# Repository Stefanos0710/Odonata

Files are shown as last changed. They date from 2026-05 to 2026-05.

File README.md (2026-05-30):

# Odonata

Odonata is an autonomous indoor drone controlled over a local network. I had the idea for the project, after I once bought a drone that broke after just two days because I struggled to control it manually. Sothat it doesn´t crash again, I decided to build a new,  autonomous drone and named it Odonata, after the Latin word for dragonfly.

The drone weighs about 300g and uses a 3S 11.1V 850mAh battery, giving it a flight time of roughly 5 minutes. With around 1100g of thrust, it achieves a 3:1 thrust-to-weight ratio, which allows precise flights. For navigation, it has 4 ToF (Time-of-Flight) sensors to track its position in the room, and it can perform controlled autonomous landings using a camera that detects AprilTags on the landing station. The landing station is designed with self-centering sticks, sothat even with a positioning error of about 1cm, the drone can still lands safely.

Odonata runs on a Raspberry Pi Zero 2W and a DarwinFPV flight controller, connected together via a custom PCB. With this setup the Pi can send and receive data using MAVLink commands (such as starting the motors, pitching, etc.). The project is split into two parts: the drone itself and a local server. The server hosts a web-based cockpit where you can monitor the drone, test the motors, and start-stop flights. Because it works locally, you can easily host the server on your laptop, PC, or a separate Raspberry Pi.

## Zine Poster

Here is the Zine poster of my project Odonata:

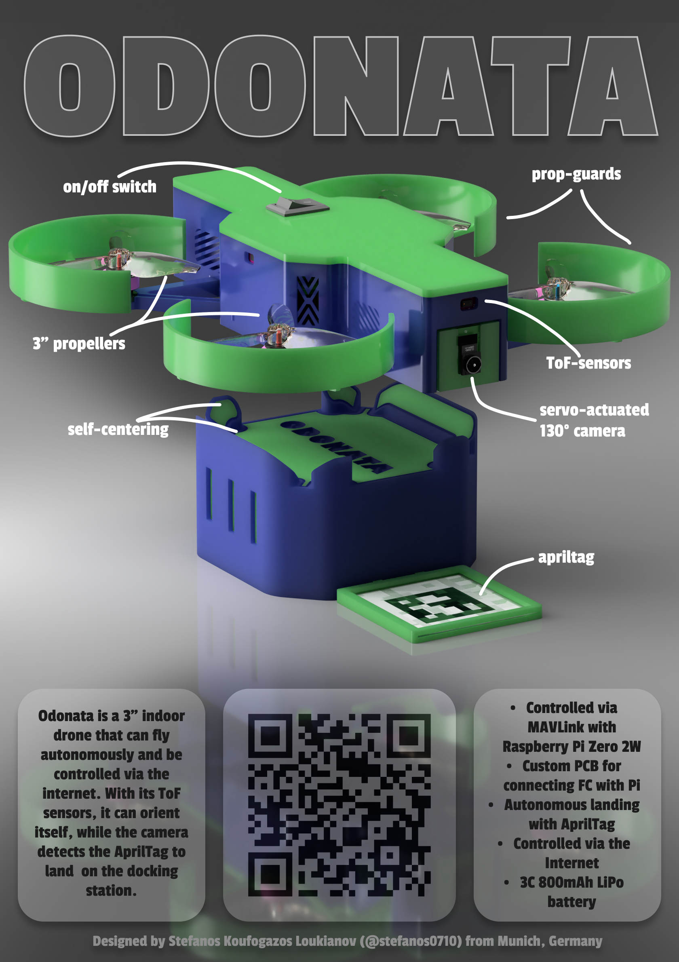
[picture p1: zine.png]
Odonata Zine


## Website/Cockpit

Here you can see the user interface of the cockpit where you can monitor the drone and send commands:
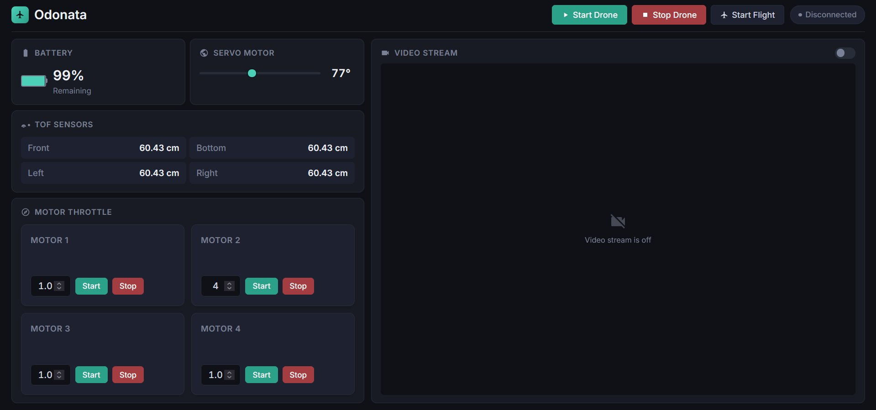
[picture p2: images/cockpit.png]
Cockpit


## CAD Model

The CAD design of Odonata is split into several parts, like the arms, the walls, the base, the cover, and the propguards. Everything is attached using M2 screws and heat inserts, or slide-ins and snap-fits. The .step, .stl and f3d/f3z files can be found at the /CAD directory. Here are some nice renders of the assembled drone:

(All parts were modeled and rendered in Autodesk Fusion 360)

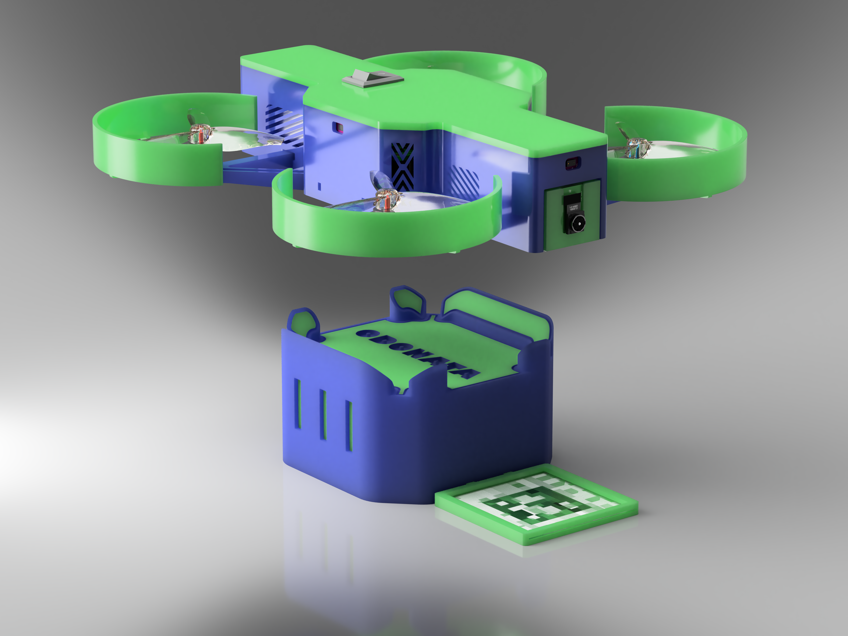
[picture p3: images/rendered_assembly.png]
Landing Station Assembly


<details>
<summary><b>Click here to view more renders</b></summary>

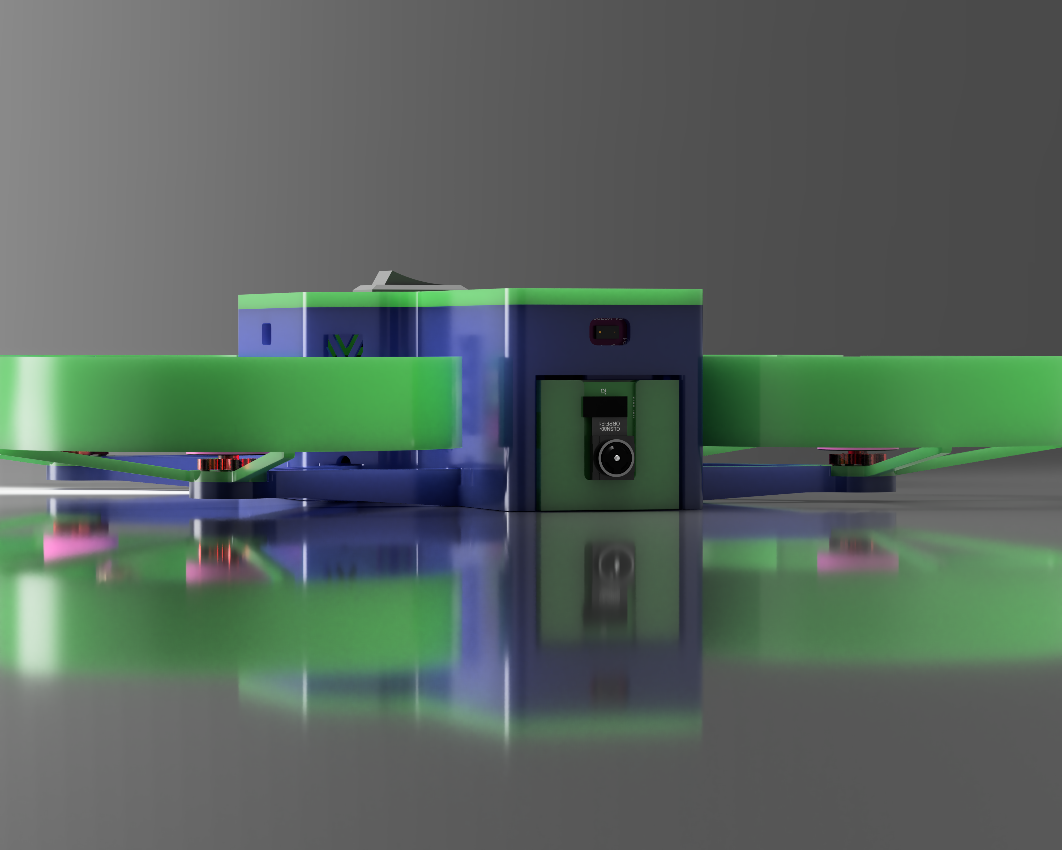
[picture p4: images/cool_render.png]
Cool Drone Render

Close Up Render
Drone on Floor

</details>

## PCB

This custom PCB is designed in KiCad and makes the flawless communication between the Flight Controller and the Raspberry Pi Zero 2W possible, and also connects the servo, the ToF sensors and camera to a working system. It uses a 4-layer design for the optimal routing and to ensure no noise on the power lines.

### Schematics

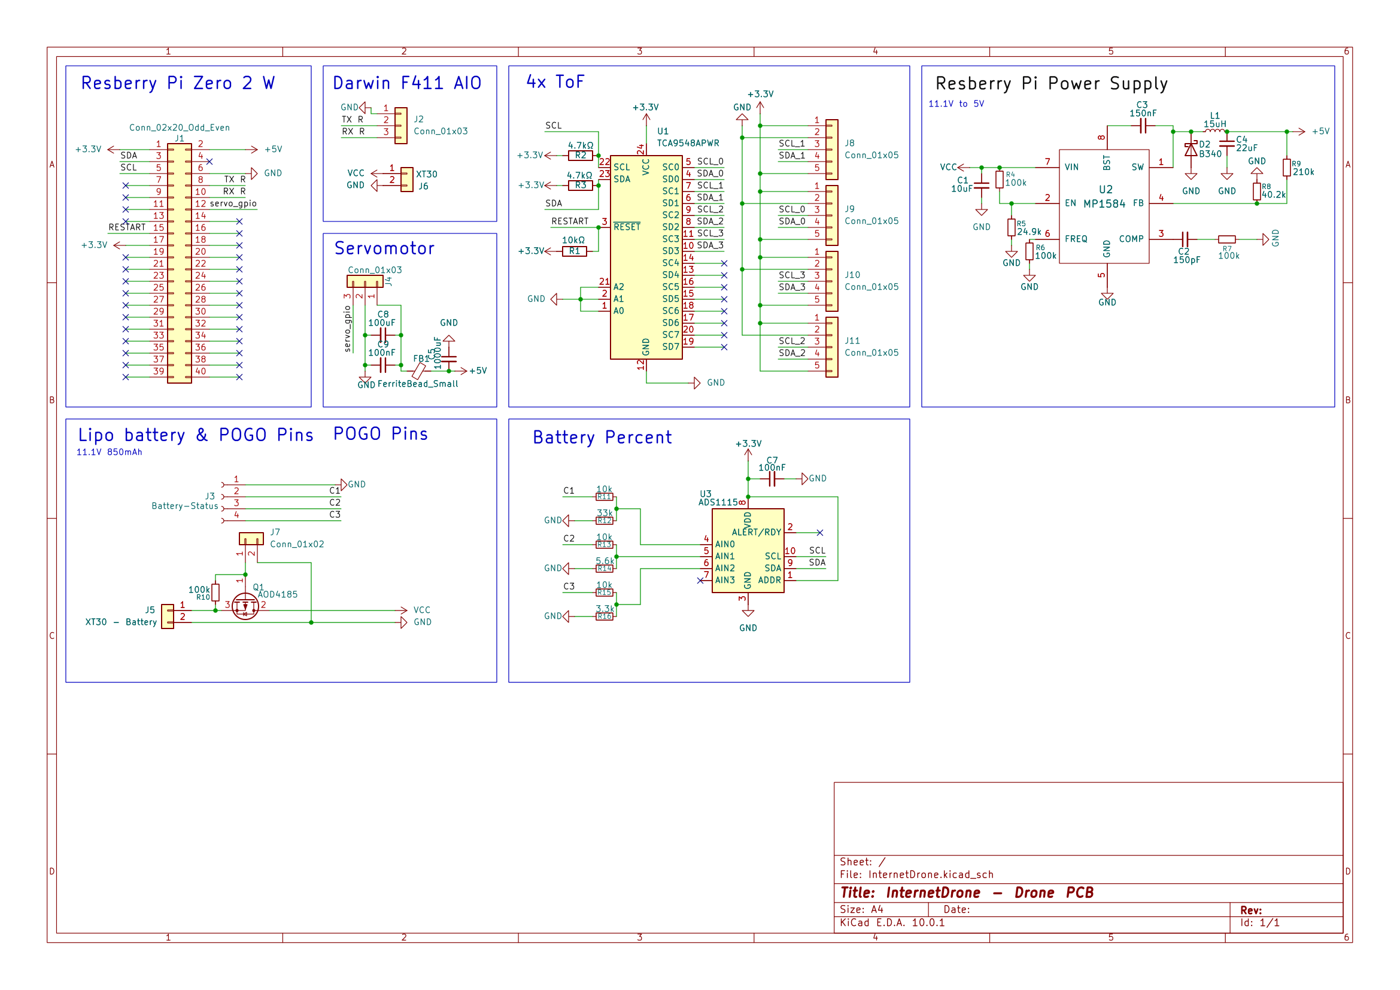
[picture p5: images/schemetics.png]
Schematics


### PCB-Layers

The PCB uses 4 layers: 1. TOP-Signal layer 2. GND layer 3. Power layer 4. Signal and GND layer

#### **1. Layer (Top-Signal)**

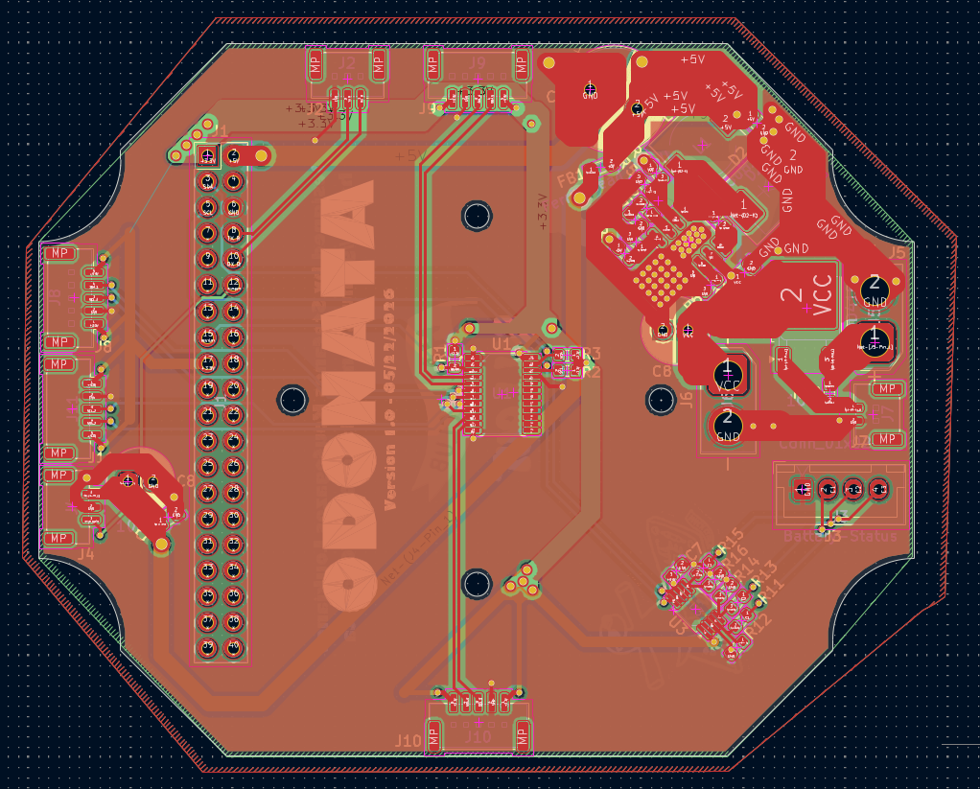
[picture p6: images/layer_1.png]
1. Layer


#### **2. Layer (GND)**

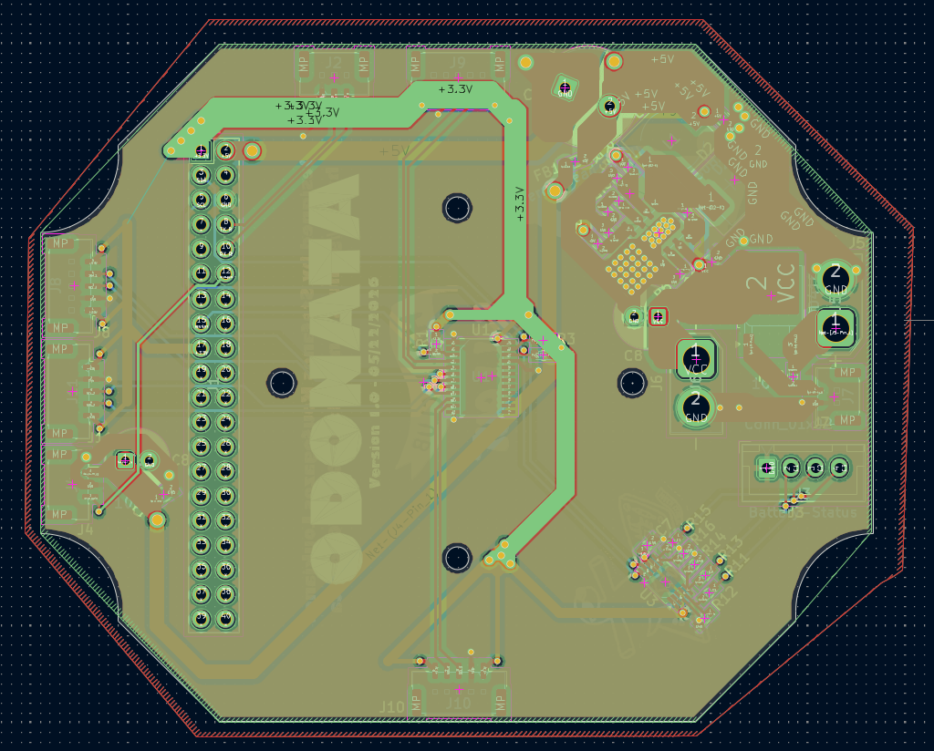
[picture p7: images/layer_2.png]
2. Layer


#### **3. Layer (Power)**

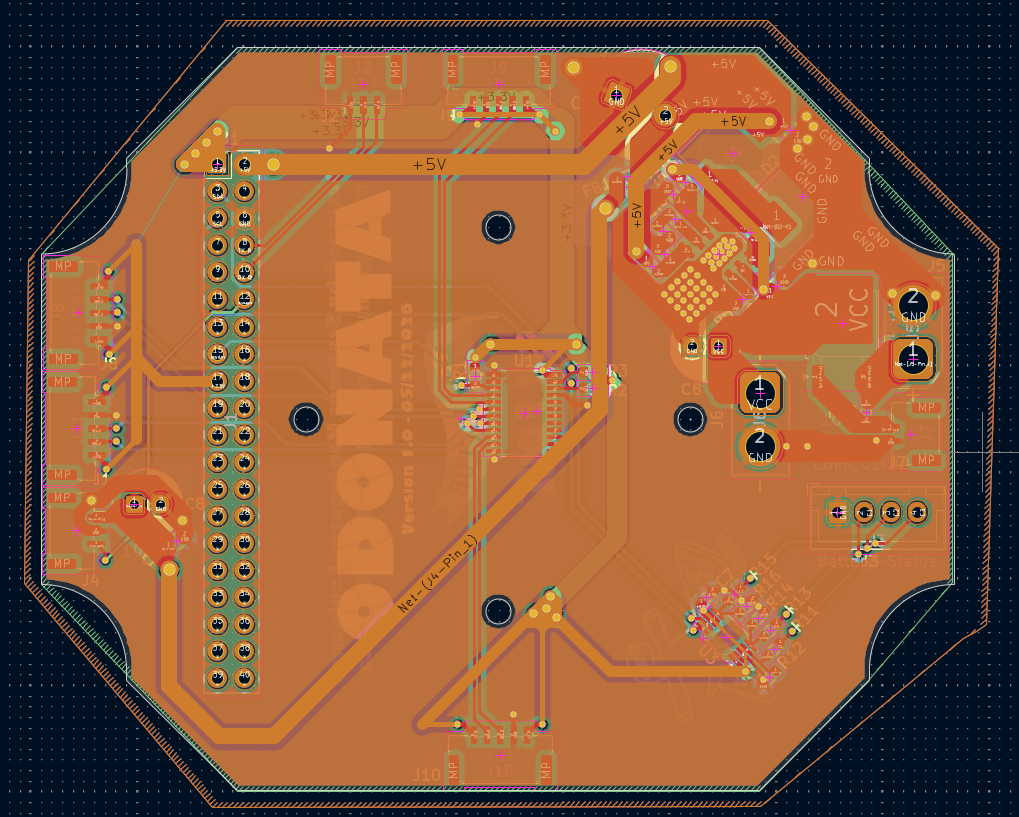
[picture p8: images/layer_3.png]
3. Layer


#### **4. Layer (Signal/GND)**

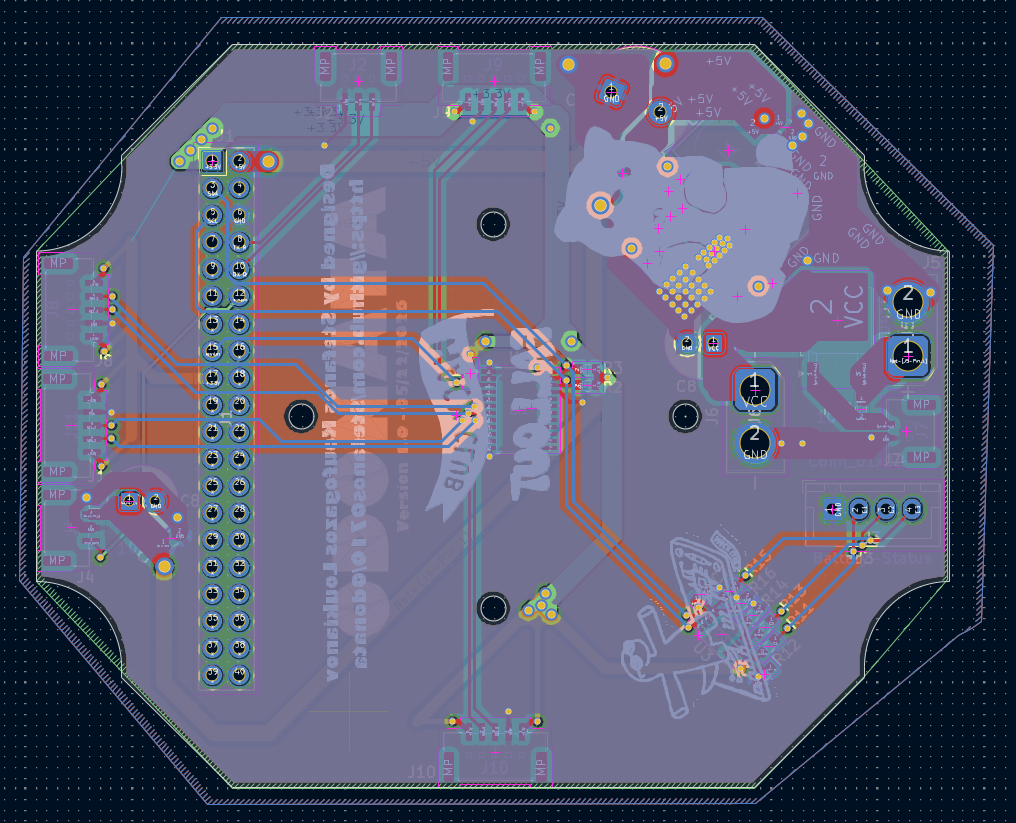
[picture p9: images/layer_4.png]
4. Layer


#### **PCB 3D-Rendering**

| Front | Back |
|---|---|
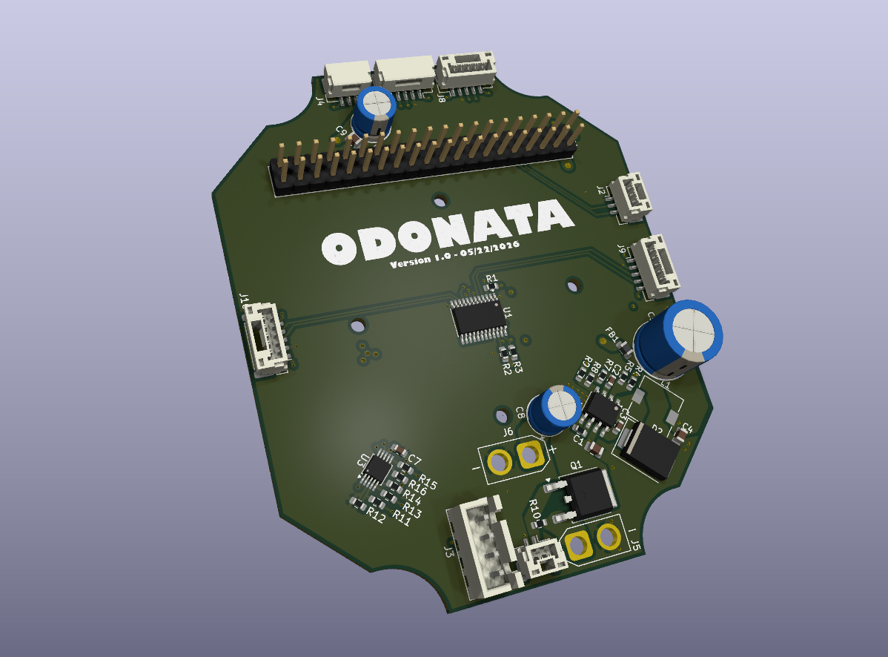
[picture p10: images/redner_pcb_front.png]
Front
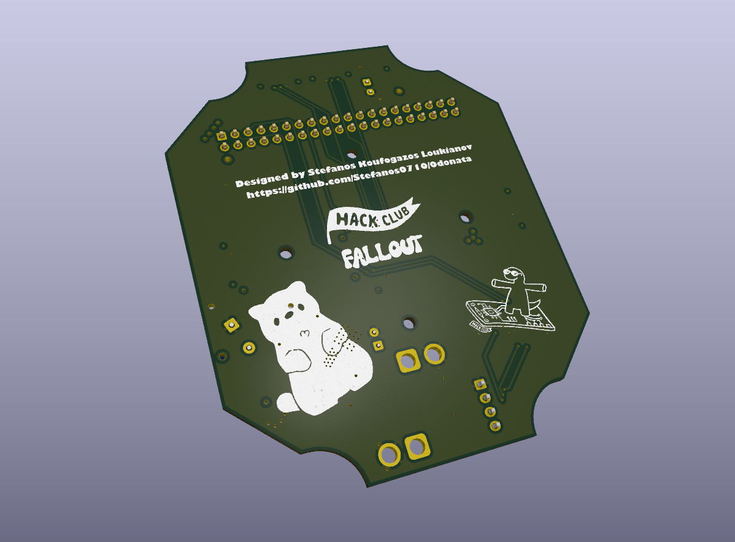
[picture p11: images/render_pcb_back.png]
Back
|  |  |

#### JLCPCB Order

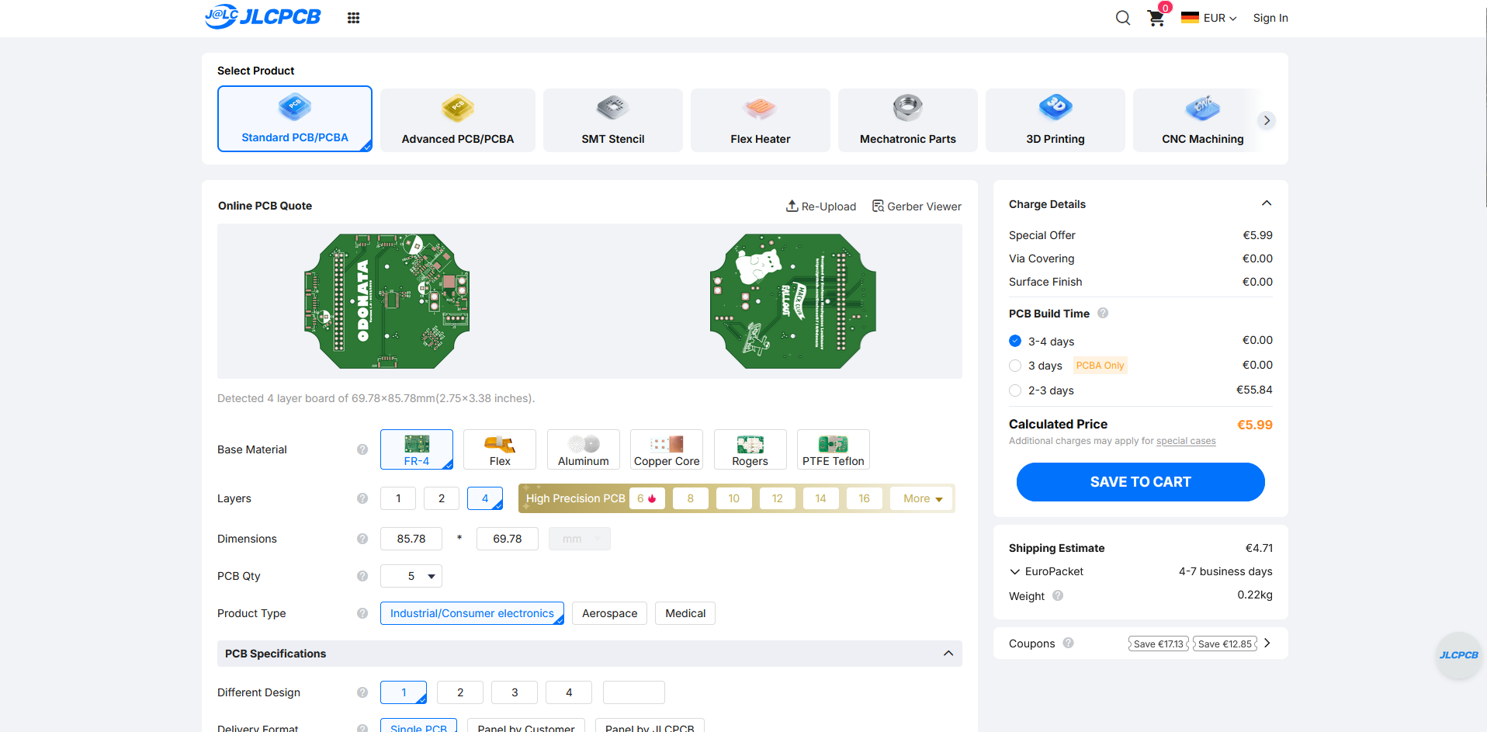
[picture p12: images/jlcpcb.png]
JLCPCB


## How to build Odonata (Step-by-Step)

If you want to rebuild this drone without any modifications, you can follow these next steps. If you want to modify the drone, you can follow along the guide, you just have to adjust it to your changes:

### 1. Getting the parts

1. Download the whole repository on your computer by running these commands in your terminal to download the firmware, CAD, and PCB:

   ```bash
   git clone https://github.com/Stefanos0710/Odonata.git
   cd Odonata
   ```

   After that, you will have cloned the entire project onto your computer.

2. Next, you have to print out the 3D parts, and therefore you have 2 options, based on whether you have a 3D printer or not:
   1. If you have a 3D printer: upload the stl files from `/CAD/f3d_stl` into your slicer software. You have to print every file separately. So for the propguards you need 4, the motor arms you need 4, the base you need 1, the wall you need 1, the cover you need 1, and you need the camera holder. For the landing station, you need the catcher and the AprilTag holder.
   2. If you don't have a 3D printer, you can use a company like PCBWay, JLCPCB, or any other 3D printing service. There you have to upload the exact same files I mentioned previously and order them.
   3. Overall for the filament, if you can choose which one you can use, I would assume to use TPU for the propguards and print the rest with PETG for the best stability. For the color, if you like the style of the drone, it should be light/lime green and purple/blue.

3. Next, you should order the PCB. Therefore you need the gerber files which you find at `PCB/gerbers` as a `gerbers.zip` file. This file you can upload on a service like PCBWay, JLCPCB, or any other of your choice. Make sure to select 4 layers, and for the color it doesn't matter, but in this case I used the typical green one. Otherwise, I use the default options, so FR-4 as material.

4. Next, we need to get/buy the rest of the parts. A list with all parts you can find further down in the README, or in the `BOM.csv` file. There is the cost of the parts, the links, name, and description. INFO: the shipping cost is calculated for ordering to Bavaria, Germany, so it might change for you. But the rough price without shipping is 222,71€.

### 2. Setting up the Raspberry Pi Zero 2 W

After you got all the parts, we can start building the drone. And therefore we will start setting up the Raspberry Pi Zero 2 W:

1. Firstly, you need to download the Raspberry Pi Imager software on your computer, so that you can install the OS on the Raspberry Pi. First open this site https://www.raspberrypi.com/software/ and download it for your OS (Windows/macOS/Linux).
2. After downloading, you need to attach a micro SD card with at least 16GB to the computer, so that you can flash the OS and attach it later into the Raspberry Pi.
3. Then you choose the Raspberry Pi OS Lite, without the desktop, so that we don't waste resource power on that.
4. During that procedure, you will need to add the name (I assume to use "odonata" as the name), the WLAN (this must match the WLAN that you are connected to with your computer and later your server), and very important is to activate SSH, and lastly, you have to add a username and a password.
5. Then you detach the micro SD from your computer and attach it into the Raspberry Pi and connect it with a USB for power.
6. After waiting for about 5 min so that the OS can boot, you can type (for Windows):

   ```bash
   ssh yourusername@odonata.local
   ```

   And so you should be connected to the Raspberry Pi.
7. Now we update the system by typing in:

   ```bash
   sudo apt update
   sudo apt upgrade -y
   ```

8. After that, type in `sudo raspi-config` and activate the camera, the SPI, and the I2C.
9. After that, we have to install Python and Git. It's mostly already installed, but to update it's good:

   ```bash
   sudo apt install python3 python3-pip python3-venv git -y
   python3 --version
   pip3 --version
   git --version
   ```

   If you see no error, then everything is fine and installed.
10. And lastly, you have to copy the drone folder from firmware to the Raspberry Pi, and you can do it with this:

   ```bash
   git clone --depth 1 https://github.com/Stefanos0710/Odonata.git temp_repo
   mv temp_repo/firmware/drone ./drone
   mv temp_repo/firmware/requirements.txt ./
   rm -rf temp_repo

   cd drone
   pip install -r requirements.txt
   ```

11. Then, to activate the communication with the FC, you have to also add in `sudo raspi-config` under Interface Options -> Serial Port:
    - Login shell over serial? → No
    - Enable serial hardware? → Yes
    And then reboot.

### 3. Flight Controller Configuration

1. After we set up the Pi, we have to configure the FC (Flight Controller) so that we can use MAVLink on it. Therefore, you have to firstly install Mission Planner and then connect the FC with a USB cable to the PC.
2. Then you have to choose the COM port and the baud number that should be 115200, and then click Connect.
3. Then open the menu under Initial Setup and then Install Firmware, then select ArduCopter.
4. During that process, the firmware is installed and the FC is rebooted multiple times.
5. After that, you should read a text called ArduCopter Vx.x.x, and if Mission Planner connected again, then all is perfect.
6. Then we have to configure the parameters in Mission Planner. Therefore you go under Config to Full Parameter List and fill this out:
   - `SERIAL2_PROTOCOL = 2`
   - `SERIAL2_BAUD = 115`
7. This activates MAVLink2 which allows the communication with the Pi, and the baud number is the standard for drones with MAVLink. And after clicking on "Write Params", you are finished and you set everything up.

### 4. PCB Soldering

1. Now you have to solder all the SMD parts on the drone PCB. There isn't really a step-by-step for this, try to orientate yourself from the PCB renders, the schematics, and PCB layer 1.

### 5. Drone Assembly

After everything is soldered, you need to assemble the hardware parts:

1. Place the PCB on the base that was 3D printed, then add the placeholders (spacers) from the FC. Put the FC on it and screw it on with the M2 12mm screws.
2. Attach the Raspberry Pi to the male pins.
3. For the power, I firstly recommend to use a laboratory power supply so that you don't destroy your battery if something is wrong.
4. To connect everything, you need to connect the TX and RX cables from J2 with the RX and TX cables from the FC, and the rest of the parts are pretty easy to connect. Orientate yourself here again from the schematics and the PCB design.
5. Lastly run that command to install mavproxy:

   ```bash
   python3 mavproxy.py --master=/dev/serial0 --baudrate 115200 --aircraft MyCopter
   ```

6. And now we can attach the rest of the parts. Firstly, you have to insert the heat inserts with a soldering iron into the parts. Therefore you have to add them to the motor arms and the walls.
7. After that, you have to place the arms in the holding parts from the base and screw them with the M2 6mm screws into the base.
8. Next, you place the prop guards at the place where the motors go and screw them again with 6mm screws.
9. And now you have to lengthen the cables from the motors and place them in the cable canal from the arm into the inside of the drone, and solder the cables onto the FC pads for the motors.
10. Next, you have to attach the camera holder to the servo and also place the camera module into it, and place it in the front of the base. Make sure that the camera cable goes above the servo, connect the servo cable with its JST-GH cable, and attach it onto the PCB.
11. Next, solder the JST-GH cables to the ToF sensors and also add them to the PCB.
12. After all of this, you can place the walls and screw them on the base.
13. Next, place all the ToF sensors in their positions and make sure to press them in so that they hold their place. And now you are ready for the first test.

### 6. Server Setup

1. Go to your server computer or on the computer where you are currently working, and run these commands:

   ```bash
   git clone --depth 1 https://github.com/Stefanos0710/Odonata.git temp_repo
   mv temp_repo/firmware/server ./server
   mv temp_repo/firmware/requirements.txt ./
   rm -rf temp_repo

   cd server
   pip install -r requirements.txt

   fastapi dev
   ```

2. Then open `127.0.0.1:8000` and you will see the drone cockpit.
3. There you have to firstly add the IP by pressing "Connect Drone" or wait until the IP shows up, and connect the drone.
4. Then start the drone and test every motor and every component independently. If everything works fine, you are ready for the final step!

### 7. Final Touches

1. Now you can attach the propellers to the drone, and make sure they sit very tight.
2. After also attaching the battery and the on/off switch at the cover, you now have to print this paper out ([april_tag_print.pdf](images/april_tag_print.pdf)) and add it to the AprilTag holder.
3. Attach the AprilTag holder under the catcher, place the drone on the catcher, and let it start via the cockpit by pressing "Start Flight" and see the magic happen.

## BOM (Bill of Materials)

Here is a list of components and parts I used for this project:
(You can also find the csv file [here](BOM.csv))

| Name | Description | Link | Unit Cost (€) | Quantity | Price (€) | Shipping Cost | Total |
|---|---|---|---|---|---|---|---|
| C1 | 10uF 0805 Capacitor | [LCSC](https://www.lcsc.com/product-detail/C95841.html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) | 0,03 | 10,00 | 0,34 | 18,91 | |
| C2, C3 | 150pF 0603 Capacitor | [LCSC](https://www.lcsc.com/product-detail/C37298.html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) | 0,01 | 50,00 | 0,41 | 18,91 | |
| C4 | 22uF 0805 Capacitor | [LCSC](https://www.lcsc.com/product-detail/C602037.html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) | 0,00 | 100,00 | 0,48 | 18,91 | |
| C5 | 1000uF Electrolytic Capacitors 10mm*5mm | [LCSC](https://www.lcsc.com/product-detail/C1579458.html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) | 0,15 | 1,00 | 0,15 | 18,91 | |
| C7 | 100nF 0603 Capacitor | [LCSC](https://www.lcsc.com/product-detail/C77058.html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) | 0,03 | 1,00 | 0,03 | 18,91 | |
| C8 | 100uF Electrolytic 6.3mm 11mm Capacitor | [LCSC](https://www.lcsc.com/product-detail/C135785.html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) | 0,05 | 5,00 | 0,26 | 18,91 | |
| C9 | 100nF 0805 Capacitor | [LCSC](https://www.lcsc.com/product-detail/C1711.html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) | 0,01 | 50,00 | 0,35 | 18,91 | |
| D2 | Schottky-Diode 3A | [LCSC](https://www.lcsc.com/product-detail/C7436556.html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) | 0,06 | 10,00 | 0,63 | 18,91 | |
| FB1 | Ferrite Bead 0805 300 ohm 2A | [LCSC](https://www.lcsc.com/product-detail/C67451.html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) | 0,02 | 50,00 | 0,78 | 18,91 | |
| J1 | female connector with pi | [LCSC](https://www.lcsc.com/product-detail/C50980.html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) | 0,20 | 5,00 | 0,99 | 18,91 | |
| J2 | JST-GH 1x03-1MP_P1.25mm_Vertical | [LCSC](https://www.lcsc.com/product-detail/C161691.html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) | 0,67 | 1,00 | 0,67 | 18,91 | |
| J3 | JST-XH 1x04 | [LCSC](https://www.lcsc.com/product-detail/C144395.html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) | 0,05 | 10,00 | 0,48 | 18,91 | |
| J4 | JST-GH 1x03-1MP_P1.25mm_Horizontal | [LCSC](https://www.lcsc.com/product-detail/C514175.html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) | 0,12 | 5,00 | 0,60 | 18,91 | |
| J5, J6 | XT30-Female Vertical | [LCSC](https://www.lcsc.com/product-detail/C19268023.html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) | 0,21 | 5,00 | 1,06 | 18,91 | |
| J7 | JST-GH 1x02 vertical | [LCSC](https://www.lcsc.com/product-detail/C161690.html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) | 0,18 | 5,00 | 0,91 | 18,91 | |
| J8, J9, J10 | JST-GH 1x05 Vertical | [LCSC](https://www.lcsc.com/product-detail/C189891.html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) | 0,30 | 5,00 | 1,51 | 18,91 | |
| J11 | JST-GH 1x05 Horizontal | [LCSC](https://www.lcsc.com/product-detail/C189896.html?s_z=n_q_SM05B-GHS-TB) | 0,18 | 5,00 | 0,89 | 18,91 | |
| L1 | Inductor 7.3x7.3_4.5H 15uH 5A | [LCSC](https://www.lcsc.com/product-detail/C7461222.html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) | 0,88 | 1,00 | 0,88 | 18,91 | |
| Q1 | AOD4185 40V 40A | [LCSC](https://www.lcsc.com/product-detail/C5346822.html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) | 0,16 | 5,00 | 0,81 | 18,91 | |
| R1, R11, R13, R15 | SMD Resistor 0603 10k 0.5% tolerance | [LCSC](https://www.lcsc.com/product-detail/C2930027.html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) | 0,00 | 100,00 | 0,10 | 18,91 | |
| R2, R3 | 0603 4.7k 1% | [LCSC](https://www.lcsc.com/product-detail/C99782.html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) | 0,00 | 100,00 | 0,14 | 18,91 | |
| R4, R6, R7, R10 | 0603 100k 1% | [LCSC](https://www.lcsc.com/product-detail/C2906980.html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) | 0,00 | 100,00 | 0,11 | 18,91 | |
| R5 | 0603 24.9k 0,1 tolerance | [LCSC](https://www.lcsc.com/product-detail/C2654014.html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) | 0,09 | 5,00 | 0,47 | 18,91 | |
| R8 | 0603 40.2k 1% | [LCSC](https://www.lcsc.com/product-detail/C12447.html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) | 0,00 | 100,00 | 0,13 | 18,91 | |
| R9 | 0603 210k 1% | [LCSC](https://www.lcsc.com/product-detail/C54102584.html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) | 0,0183 | 20 | 0,37 | 18,91 | |
| R12 | 0603 33k | [LCSC](https://www.lcsc.com/product-detail/C2075611.html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) | 0,09 | 5,00 | 0,44 | 18,91 | |
| R14 | 0603 5.6k 0.1% | [LCSC](https://www.lcsc.com/product-detail/C445632.html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) | 0,07 | 5,00 | 0,36 | 18,91 | |
| R16 | 0603 3.3k 1% | [LCSC](https://www.lcsc.com/product-detail/C2907023.html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) | 0,0011 | 100 | 0,11 | 18,91 | |
| U1 | TCA9548APWR | [LCSC](https://www.lcsc.com/product-detail/C130026.html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) | 0,57 | 1,00 | 0,57 | 18,91 | |
| U2 | mp1584en | [LiD/Aliexpress](https://de.aliexpress.com/item/1005007196431727.html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) | 4,58 | 1,00 | 4,58 | 0 | |
| U3 | ADS1115 | [LCSC](https://www.lcsc.com/product-detail/C468683.html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) | 1,43 | 1,00 | 1,43 | 18,91 | |
| JST GH 1.25 Set | JST GH1.25 GH 1.25mm Connector Kit 2/3/4/5/6/7/8/9/10Pin Housing Pre-Crimped Cable Wire | [Aliexpress](https://de.aliexpress.com/item/1005009363803762.html) | 17,79 | 1,00 | 17,79 | 0 | |
| XT30-F cable | XT30U Amass 1PCS Male Female Connector Plug With 16 AWG | [Aliexpress](https://de.aliexpress.com/item/1005006871265256.html) | 4,73 | 1,00 | 4,73 | 0 | |
| Cable | 2 Pins Super Soft Black Red Silicone Cable | [Aliexpress](https://de.aliexpress.com/item/1005006762917521.html) | 1,08 | 1,00 | 1,08 | 0 | |
| Flight Controller | DarwinFPV F411 15A AIO (FC+ESC+RX) ELRS | [Rotorama](https://www.rotorama.de/product/darwinfpv-f411-15a-aio-fc-esc-rx-elrs) | 53,39 | 1,00 | 53,39 | 0 | |
| Motors | Happymodel EX1204 5000KV 3S 3" Motor | [Aliexpress](https://de.aliexpress.com/item/1005003283337242.html#nav-review) | 37,79 | 1,00 | 37,79 | 0 | |
| Props | Gemfan Hurricane 3016 3inch Toothpick 3X1.6X3 3-Blade PC Propeller | [Aliexpress](https://de.aliexpress.com/item/1005003324572840.html) | 7,89 | 1,00 | 7,89 | 0 | |
| Battery | Tattu 3S Lipo Battery 850 mAh 11.1 V 150C 3S1P | [Amazon](https://www.amazon.de/TATTU-850mAh-Battery-Stecker-Drohnen/dp/B0CXDKXJLP) | 23,99 | 1,00 | 23,99 | 0 | |
| Raspberry Pi Zero 2 W | Raspberry Pi Zero 2 W | [Pi-Shop](https://www.pi-shop.ch/raspberry-pi-zero-2-w) | 19,53 | 1,00 | 19,53 | 13,5 | |
| Camera | 130° 8MP Camera | [Aliexpress](https://de.aliexpress.com/item/1005007274396582.html#nav-review) | 8,11 | 1,00 | 8,11 | 0 | |
| ToF Sensor | VL53L0X Time-of-Flight (ToF) Laser Ranging Sensor Breakout 940nm | [Aliexpress](https://de.aliexpress.com/item/1005008557812009.html) | 3,24 | 4,00 | 12,96 | 0 | |
| PCB | 4 Layer custom PCB | [JLCPCB](https://cart.jlcpcb.com/quote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) | 5,99 | 1,00 | 5,99 | 7,81 | |
| Raspberry Pi Pin Header | BOOMELE(Boom Precision Elec) 2.54-2*20P | [LCSC](https://www.lcsc.com/product-detail/Female-Headers_BOOMELE-Boom-Precision-Elec-C50982_C50982.html) | 0,26 | 5,00 | 1,29 | 18,91 | |
| Screw 6mm | 50pcs Black 304 Stainless Steel Cross Phillips CM M2 6mm | [Aliexpress](https://de.aliexpress.com/item/1005005618746295.html) | 2,00 | 1,00 | 2,00 | 0 | |
| Screw 12mm | 50pcs Black 304 Stainless Steel Cross Phillips CM M2 12mm | [Aliexpress](https://de.aliexpress.com/item/1005005618746295.html) | 2,52 | 1,00 | 2,52 | 0 | |
| Heat insert | 50pcs M2 2mm | [Aliexpress](https://de.aliexpress.com/item/1005008318533389.html) | 2,66 | 1,00 | 2,66 | 0 | |
| Switch | KCD1 15*21mm 2 Pin Boat Switch | [Aliexpress](https://de.aliexpress.com/item/1005007987928702.html) | 0,38 | 5,00 | 1,90 | 18,91 | |
| Servo | SG90 | [Aliexpress](https://de.aliexpress.com/item/1005008107550639.html) | 1,91 | 1,00 | 1,91 | 0 | |
| **Sum Costs** |  |  |  |  | **224,62** | **40,22** | **264,84** |

Huge thanks to Fallout from Hack Club for inspiring me to build this project and for financing it!

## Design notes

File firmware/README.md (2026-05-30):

# Firmware

This part of the project contains the firmware for the drone Odonata. The code is split into two parts: the software running on the drone itself and the control server with the cockpit.

## Drone (/drone)
This folder has the scripts for the drone's computer (Raspberry Pi Zero 2 W). These files:

* **main.py**: The main program that manages the drone's logic, flights and tests, runs the main loop, and handles communication with the server.
* **motor.py**: Defines commands into signals for the flight controller to move the 4 motors.
* **camera.py**: Captures and processes the video feed from the drone's camera.
* **servo.py**: Controls the movement of the servo motor.
* **tof_sensor.py**: Reads distance data from the ToF sensor (used for altitude height measurement).
* **battery_status.py**: Measures the battery percentage (converts voltage to percent).

## Server (/server)
This folder contains the cockpit and the communication scripts for the server.

* **main.py**: The backend code that hosts the server. It receives and sends commands from the drone and represents them in the Odonata cockpit.
* **frontend/**: The web-based cockpit that you open in your browser to monitor and control the drone.
  * **index.html**: The structure and layout of the control dashboard in HTML.
  * **static/script.js**: The logic of the website (handling button clicks, joystick inputs, and video streaming).
  * **static/style.css**: The styling of the website.

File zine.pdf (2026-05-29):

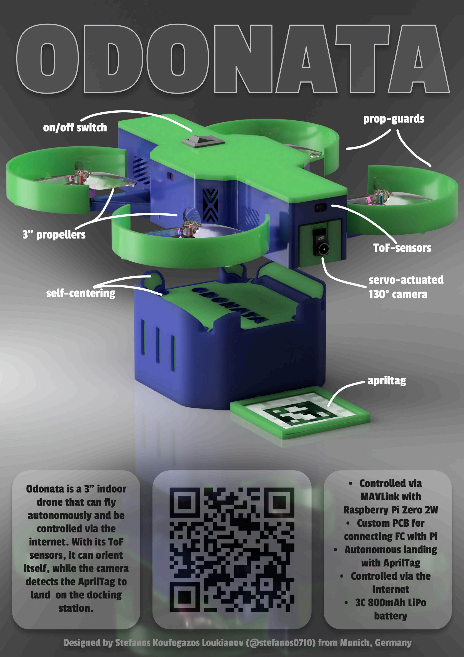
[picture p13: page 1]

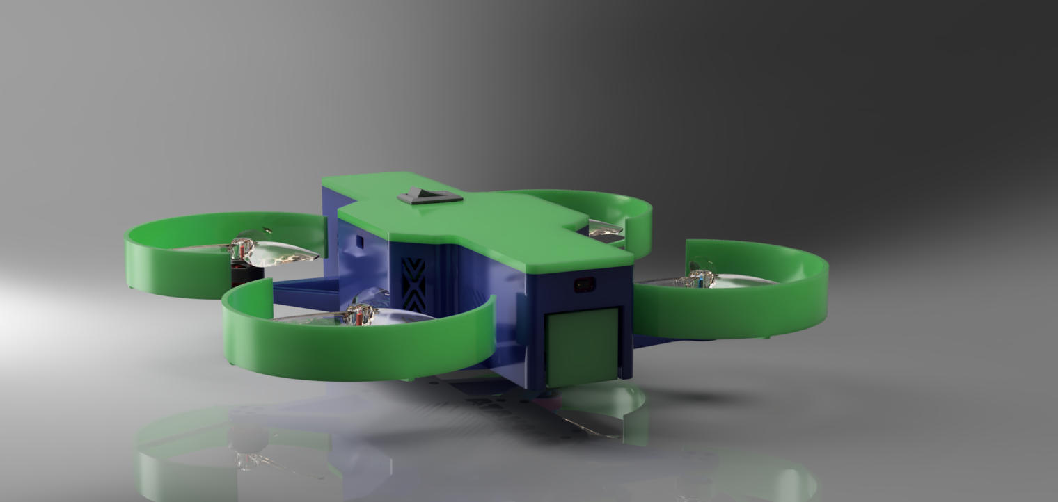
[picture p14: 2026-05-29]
images/render.PNG

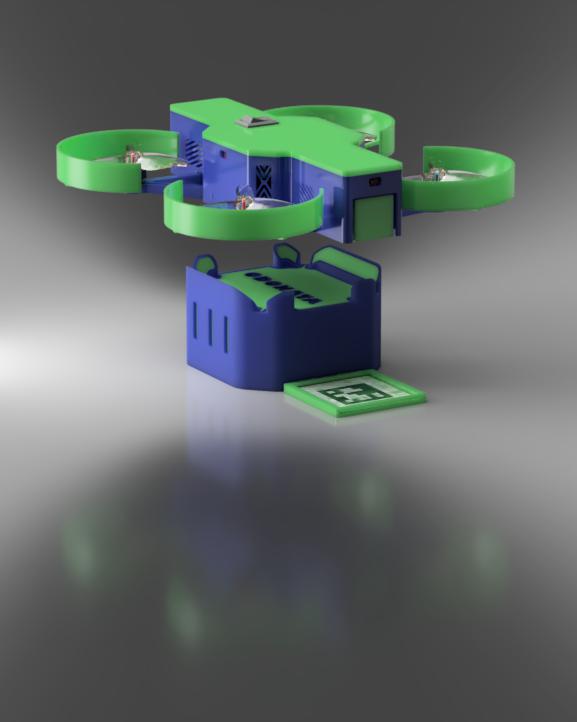
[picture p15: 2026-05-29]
images/render_2.jpg

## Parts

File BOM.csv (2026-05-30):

Name | Description | Link | Unit Cost in € | Quantity | Price in € | Shipping Cost | Total
C1 | 10uF 0805 Capacitor | https://www.lcsc.com/product-detail/C95841.html?s_z=n_q_t_Capacitors | 0,03 | 10,00 | 0,34 | 18,91
C2, C3 | 150pF 0603 Capacitor | https://www.lcsc.com/product-detail/C37298.html?s_z=n_q_t_Capacitors | 0,01 | 50,00 | 0,41 | 18,91
C4 | 22uF 0805 Capacitor | https://www.lcsc.com/product-detail/C602037.html?s_z=n_q_t_Capacitors | 0,00 | 100,00 | 0,48 | 18,91
C5 | 1000uF Electrolytic Capacitors 10mm*5mm | https://www.lcsc.com/product-detail/C1579458.html?s_z=n_q_ESY108M010AH2EA%2520 | 0,15 | 1,00 | 0,15 | 18,91
C7 | 100nF 0603 Capacitor | https://www.lcsc.com/product-detail/C77058.html?s_z=s_c_Ceramic%2520Capacitors | 0,03 | 1,00 | 0,03 | 18,91
C8 | 100uF Electrolytic 6.3mm 11mm Capacitor | https://www.lcsc.com/product-detail/C135785.html?s_z=s_p_35PX100MEFC6.3X11 | 0,05 | 5,00 | 0,26 | 18,91
C9 | 100nF 0805 Capacitor | https://www.lcsc.com/product-detail/C1711.html?s_z=s_c_Ceramic%2520Capacitors | 0,01 | 50,00 | 0,35 | 18,91
D2 | Schottky-Diode 3A | https://www.lcsc.com/product-detail/C7436556.html?s_z=n_q_B340%2520DO-214AB | 0,06 | 10,00 | 0,63 | 18,91
FB1 | Ferrite Bead 0805 300 ohm 2A | https://www.lcsc.com/product-detail/C67451.html | 0,02 | 50,00 | 0,78 | 18,91
J1 | femal connentor with pi | https://www.lcsc.com/product-detail/C50980.html | 0,20 | 5,00 | 0,99 | 18,91
J2 | JST-GH 1x03-1MP_P1.25mm_Vertical | https://www.lcsc.com/product-detail/C161691.html?s_z=n_q_BM03B-GHS-TBT | 0,67 | 1,00 | 0,67 | 18,91
J3 | JST-XH 1x04 | https://www.lcsc.com/product-detail/C144395.html?s_z=s_p_B4B-XH-A%28LF%29%28SN%29 | 0,05 | 10,00 | 0,48 | 18,91
J4 | JST-GH 1x03-1MP_P1.25mm_Horizontal | https://www.lcsc.com/product-detail/C514175.html?s_z=s_p_SM03B-GHS-TB%28LF%29%28SN%29 | 0,12 | 5,00 | 0,60 | 18,91
J5, J6 | XT30-Female Vertical | https://www.lcsc.com/product-detail/C19268023.html?s_z=n_q_Amass%2520XT30U%2520 | 0,21 | 5,00 | 1,06 | 18,91
J7 | JST-GH 1x02 vertical | https://www.lcsc.com/product-detail/C161690.html?s_z=n_q_BM02B-GHS-TBT | 0,18 | 5,00 | 0,91 | 18,91
J8, J9, J10 | JST-GH 1x05 Vertical | https://www.lcsc.com/product-detail/C189891.html?s_z=n_q_BM05B-GHS-TBT | 0,30 | 5,00 | 1,51 | 18,91
J11 | JST-GH 1x05 Horizontal | https://www.lcsc.com/product-detail/C189896.html?s_z=n_q_SM05B-GHS-TB | 0,18 | 5,00 | 0,89 | 18,91
L1 | Inductor 7.3x7.3_4.5H 15uH 5A | https://www.lcsc.com/product-detail/C7461222.html | 0,88 | 1,00 | 0,88 | 18,91
Q1 | AOD4185 40V 40A | https://www.lcsc.com/product-detail/C5346822.html?s_z=n_q_AOD4185 | 0,16 | 5,00 | 0,81 | 18,91
R1, R11, R13, R15 | SMD Resistor 0603 10k 0.5% tolerance | https://www.lcsc.com/product-detail/C2930027.html?s_z=s_q_t_RESISTOR%252010K%25CE%25A9 | 0,00 | 100,00 | 0,10 | 18,91
R2, R3 | 0603 4.7k 1% | https://www.lcsc.com/product-detail/C99782.html?s_z=n_q_t_0603%25204.7k%25201%2525 | 0,00 | 100,00 | 0,14 | 18,91
R4,R6,R7,R10 | 0603 100k 1% | https://www.lcsc.com/product-detail/C2906980.html?s_z=n_q_t_0603%2520100k%25201%2525 | 0,00 | 100,00 | 0,11 | 18,91
R5 | 0603 24.9k 0,1 tolerance | https://www.lcsc.com/product-detail/C2654014.html?s_z=n_q_0603%252024.9k%25200.5%2525 | 0,09 | 5,00 | 0,47 | 18,91
R8 | 0603 40.2k 1% | https://www.lcsc.com/product-detail/C12447.html?s_z=n_q_t_0603%252040.2k%25200%252C1%2525 | 0,00 | 100,00 | 0,13 | 18,91
R9 | 0603 210k 1% | https://www.lcsc.com/product-detail/C54102584.html?s_z=n_q_t_210k%25200603 | 0,0183 | 20 | 0,37 | 18,91
R12 | 0603 33k | https://www.lcsc.com/product-detail/C2075611.html?s_z=n_q_t_0603%252033k%25200.1%2525 | 0,09 | 5,00 | 0,44 | 18,91
R14 | 0603 5.6k 0.1% | https://www.lcsc.com/product-detail/C445632.html?s_z=n_q_0603%25205.6k%25200.1%2525 | 0,07 | 5,00 | 0,36 | 18,91
R16 | 0603 3.3k 1% | https://www.lcsc.com/product-detail/C2907023.html?s_z=n_q_t_3.3k%25200603 | 0,0011 | 100 | 0,11 | 18,91
U1 | TCA9548APWR | https://www.lcsc.com/product-detail/C130026.html?s_z=n_q_TCA9548APWR | 0,57 | 1,00 | 0,57 | 18,91
U2 | mp1584en | https://de.aliexpress.com/item/1005007196431727.html?curPageLogUid=jxjSNTFxpzz5 | 4,58 | 1,00 | 4,58 | 0
U3 | ADS1115 | https://www.lcsc.com/product-detail/C468683.html?s_z=n_q_t_ADS1115 | 1,43 | 1,00 | 1,43 | 18,91
JST GH 1.25 Set | JST GH1.25 GH 1.25mm Connector Kit 2/3/4/5/6/7/8/9/10Pin Housing Pre-Crimped Cable Wire | https://de.aliexpress.com/item/1005009363803762.html?curPageLogUid=nAMXZhYGHdUi | 17,79 | 1,00 | 17,79 | 0
XT30-F cable | XT30U Amass 1PCS Male Female Connector Plug With 16 AWG | https://de.aliexpress.com/item/1005006871265256.html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 | 4,73 | 1,00 | 4,73 | 0
Cable | 2 Pins Super Soft Black Red Silicone Cable | https://de.aliexpress.com/item/1005006762917521.html?curPageLogUid=uZbdRalUVKRo | 1,08 | 1,00 | 1,08 | 0
Flight Controller | DarwinFPV F411 15A AIO (FC+ESC+RX) ELRS | https://www.rotorama.de/product/darwinfpv-f411-15a-aio-fc-esc-rx-elrs | 53,39 | 1,00 | 53,39 | 0
Motors | Happymodel EX1204 5000KV 3S 3" Motor | https://de.aliexpress.com/item/1005003283337242.html#nav-review | 37,79 | 1,00 | 37,79 | 0
Props | Gemfan Hurricane 3016 3inch Toothpick 3X1.6X3 3-Blade PC Propeller 1.5mm 2mm Hole for RC FPV Racing Drone 1303 5000KV Motor 6 pairs | https://de.aliexpress.com/item/1005003324572840.html?curPageLogUid=U8GL3VqOsc0h | 7,89 | 1,00 | 7,89 | 0
Battery | Tattu 3S Lipo Battery 850 mAh 11.1 V 150C 3S1P Battery with XT30 Connector for 3 to 5 Inch FPV Drones | https://www.amazon.de/TATTU-850mAh-Battery-Stecker-Drohnen/dp/B0CXDKXJLP | 23,99 | 1,00 | 23,99 | 0
Resberry Pi Zero 2 W | Resberry Pi Zero 2 W | https://www.pi-shop.ch/raspberry-pi-zero-2-w | 19,53 | 1,00 | 19,53 | 13,5
Camera | 130° 8MP Camera | https://de.aliexpress.com/item/1005007274396582.html#nav-review | 8,11 | 1,00 | 8,11 | 0
ToF Sensor | VL53L0X Time-of-Flight (ToF) Laser Ranging Sensor Breakout 940nm GY-VL53L0XV2 Laser Distance Module I2C IIC 3.3V/5V | https://de.aliexpress.com/item/1005008557812009.html | 3,24 | 4,00 | 12,96 | 0
PCB | 4 Layer costum PCB | https://cart.jlcpcb.com/quote?stencilLayer=4&stencilWidth=100&stencilLength=100&stencilCounts=5&plateType=1 | 5,99 | 1,00 | 5,99 | 7,81
Resberry Pi Pin Header | BOOMELE(Boom Precision Elec) 2.54-2*20P | https://www.lcsc.com/product-detail/Female-Headers_BOOMELE-Boom-Precision-Elec-C50982_C50982.html | 0,26 | 5,00 | 1,29 | 18,91
Screw 6mm | 50pcs Black 304 Stainless Steel Cross Phillips Ultra Thin Flat Wafer Head Screw CM M2 6mm | https://de.aliexpress.com/item/1005005618746295.html?curPageLogUid=XxoNdmk6hDMY | 2,00 | 1,00 | 2,00 | 0
Screw 12mm | 50pcs Black 304 Stainless Steel Cross Phillips Ultra Thin Flat Wafer Head Screw CM M2 12mm | https://de.aliexpress.com/item/1005005618746295.html?curPageLogUid=XxoNdmk6hDMY | 2,52 | 1,00 | 2,52 | 0
Heat insert | 50pcs M2 2mm | https://de.aliexpress.com/item/1005008318533389.html?curPageLogUid=AHZ569cp5Y2q | 2,66 | 1,00 | 2,66 | 0
Switch | KCD1 15*21mm 2 Pin Boat Switch | https://de.aliexpress.com/item/1005007987928702.html?curPageLogUid=QICLjLCfIq9J | 0,38 | 5,00 | 1,90 | 18,91
Servo | SG90 | https://de.aliexpress.com/item/1005008107550639.html?curPageLogUid=AHsX6x5rvIYS | 1,91 | 1,00 | 1,91 | 0
 |  |  |  |  | 222,71 | 40,22 | 262,93

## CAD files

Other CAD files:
CAD/assembly.step
CAD/drone_assembly.step
CAD/landingstation_assembly.step
CAD/f3d_stl/drone/cover.stl
CAD/f3d_stl/landingstation/catcher.stl
CAD/step/drone/arm.step
CAD/step/landingstation/catcher.step
CAD/f3d_stl/drone/motor_arm.stl
CAD/f3d_stl/landingstation/april_tag_holder.stl
CAD/step/drone/wall.step
CAD/step/landingstation/april_tag_holder.step
CAD/f3d_stl/drone/platform.stl
CAD/step/drone/cover.step
CAD/f3d_stl/drone/wall.stl
CAD/step/drone/propguards.step
CAD/f3d_stl/drone/cameraholder.stl
CAD/step/drone/platform.step
CAD/f3d_stl/drone/propguards.stl
CAD/assembly.f3z
CAD/drone_assembly.f3z
CAD/f3d_stl/drone/motor_arm.f3d
CAD/f3d_stl/drone/propguards.f3d
CAD/f3d_stl/landingstation/april_tag_holder.f3d
CAD/f3d_stl/landingstation/catcher.f3d
CAD/landingstation_assembly.f3d
CAD/step/drone/cameraholder.step

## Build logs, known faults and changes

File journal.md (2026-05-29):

# Odonata — Journal Export

- Exported at: 2026-05-29T18:32:10Z
- Project ID: 130
- Entries: 32

## Entry 1
- ID: 3456
- Author: Stefanos
- Created At: 2026-04-22T21:31:00Z

### Content

### 22. April: Find out the basics and plan the fundamental 

Before I started, I only had a rough idea. I wanted to build a drone that can mostly fly on its own and also has a docking station for charging and keeping it safe. I also already had in mind that I want to use a Raspberry Pi as a kind of brain for internet control and later video stream, but I didn’t really know yet how I would integrate that into the drone.



Since I never built a drone before and had almost no experience in this field, I started from zero and learned (by doing):

1. what a drone actually is  
2. how a drone works (lift, motors, control)  
3. what parts are needed and what they do  

This was important because otherwise every part I would pick later would feel random and would probably be wrong

After I saw that there are multiple drone layouts, like X, H and +, I chose the X design because:
- it is the most stable in flight  
- it is mostly used for indoor flying  
- it is easier to build for beginners  



Then I learned that every drone is controlled by a flight controller (FC).

At first I thought they were almost the same and that I could just buy one and it would be fine, but there are HUGE differences.

There are a lot of different FCs and every choice depends on something else: frame size, sensors, voltage, UARTs, software, etc.

This is where I really got stuck in a loop:

I would pick a part, then realize another part doesn’t match, then change that part, and suddenly the first one doesn’t fit anymore. T-T

So it became like:
- choose FC, changes motor choice  
- choose motor, changes battery  
- choose battery, changes weight  
- weight, changes whole frame idea  

And then I had to go back again.

It felt like building one decision always breaks another decision...

Another HUGE problem was that:
- many parts were not available in local shops  
- some parts were completely sold out  
- China shops were (only sometimes) cheaper but had long delivery times (3 weeks, which was too long...)

But after a long time of searching I finally found some pretty good components for my drone.

At the same time I also shaped the system idea more clearly: the Raspberry Pi should not control the motors directly, but instead be as a higher level controller for things like internet connection, remote control and later video streaming, while the flight controller handles the real-time flight control. That split made the whole architecture much clearer.

At first I wanted an F4 flight controller with Betaflight because it is:
- powerful enough  
- widely used  

But then I ran into the same problem as before:
- many were too expensive  
- many were out of stock  
- some had long shipping delays  

So after a lot of switching and comparing, I decided on the:

**DarwinFPV F411 15A AIO**

because it was available, fit perfectly in the budget and supports all other parts that I chose.

The next problem I ran into was the weight / thrust ratio

At first my setup gave only ~2:1 thrust ratio.

That is theoretically enough to fly, but extremely slow and unstable.

So I decided to upgrade motors from 1104 to 1204 size

So I lastly decided on the **Happymodel 1204 5000KV**, because it has very good thrust, is compatible with the other components and is pretty cheap with fast delivery.

To combine everything, I adjusted the full system with the right battery:
> Tattu R-Line 850mAh 3S 150C

and for the props:
> Gemfan Hurricane 3016 (3 inch)

After checking again if everything was compatible with each other, I had my final components :

- FC: DarwinFPV F411 15A AIO  
- Motor: Happymodel 1204 5000KV  
- Battery: 3S 850mAh  
- Props: Gemfan 3016  

Estimated thrust:
~280g per motor × 4 = ~1120g total

This gives around a 3.7:1 thrust ratio, which is actually solid for this drone!

Pretty happy with the progress and learned very much!

### Recording Links

- https://lookout.hackclub.com/api/media/b6f6d021-7fbb-4be1-8b2f-5608a45261e2/video.mp4
- https://lookout.hackclub.com/api/media/3165a61b-8592-4b2d-a718-28b1a420eed7/video.mp4

## Entry 2
- ID: 3587
- Author: Stefanos
- Created At: 2026-04-23T18:17:14Z

### Content

### 23. April: Finished searching the main parts!

First of all, I searched for a raspberry pi. I decided to use the Raspberry Pi Zero 2 W because it is smaller than a Pi 4, but still powerful enough, has enough pins for sensors, FC, cameras etc., and is not too expensive.

I checked the official resellers for the Pi Zero 2 W and unfortunately only FUNK 24 Aachen had it in stock. All other shops were sold out, so I ended up with a price of about 23€, which is still good.

Next, I wanted to add cameras for automatic landing with April-tags, and another one for controlling the drone over the internet (video stream) or later object detection. But I wasn’t sure if it would be possible to connect 2 cameras to the Raspberry Pi Zero 2 W and if that would be too expensive

So I searched a bit and found out that there are devices from ArduCam that can connect 2 or more cameras and connect them into one camera interface (Raspberry Pi Multi Camera Adapter)

Then I searched for the cameras. One thing that shocked me was the price (around 20–30€ per camera), but luckily AliExpress helped :)

But then I had another decision/problem:
there were multiple camera angle options (77° / 130° / 160° / 200°)

After checking some examples and thinking about the recognision of the tags, I came up with this:
- the camera for landing needs a wide enough view to detect AprilTags even if the drone is not perfectly aligned  
- 77° is too narrow,
- 160° / 200° are too large, which makes picture curve -> detection harder  
- 130° is the sweet spot!

So I decided on 130° cameras

Then I moved to the connection problem. I wanted 2 cameras, but the Raspberry Pi Zero 2 W only has one CSI camera input.

So again I searched and found the ArduCam Multi Camera Adapter (V2.2), which allows multiple cameras on one Pi. But it was quite expensive (around 40–50€), and even on AliExpress it was still expensive and not really worth it for my budget.

At this point I thought about another solution: instead of using 2 cameras, I could just use one camera and move it with a servo motor (tilt up/down). 
That would be lighter and cheaper:

- Servo weight: ~6g  
- Camera weight: ~10g  
- Servo cost: basically 0€ (I already have one)

So I decided to go with the servo solution instead of the multi-camera adapter, even though 2 cameras would be nicer. But it just didn’t make sense...

Here is an example of how the servo camera setup would work:



Additionally, I wanted to use distance sensors for more stable, controlled and safe flight (especially for landing without crashing).

The idea was to measure distance on the left/right side and front/ground side.

Here is a small drawing of the sensor placement:



While researching, I learned that there are a few common sensor types:
- ultrasonic distance sensors  
- ToF (Time of Flight) sensors  
- IR distance sensors  
- (and a few others)

After comparing pros and cons, I decided to use the VL53L0X ToF sensor, because:
- it is accurate for short distances (under ~2 meters)  
- it is small and light
- it is cheap (~3€ on AliExpress)  

Now I have found all the main parts I need for the project, including good prices, availability, and shipping time.

Happy with this sessions progress. I learned a lot again. Next session will probably be PCB design!!! Yippee!!

### Recording Links

- https://lookout.hackclub.com/api/media/5040556b-7866-4573-afae-0b8f1bfa49fb/video.mp4

## Entry 3
- ID: 3825
- Author: Stefanos
- Created At: 2026-04-25T05:54:44Z

### Content

# 24 April: Drawing the first design of the drone!

Originally, I wanted to start today with the PCB, but when I thought about how everything should be connected and fit, the center of weight, and optimal design for the drone, that’s why I decided to first make a sketch and design the drone from a top view and side view (in 1:2 scale), for brainstorming positioning and finding the right distances and angles for the parts placement. Here’s how I started:

## 1. Wheelbase 

I decided to use a 180 mm wheelbase because, after looking it up for 3" propellers, the sweet spot is about 2x–2.5x the propeller diameter.

> 76 mm (propeller diameter) * 2.5 = 190  
> 76 mm * 2 = 152  
> → about 180 mm is best for me and indoor use because I have a bit more room, also for the Raspberry Pi, FC, etc. (which will become a problem soon T-T).

So the nearest motor-to-motor distance is about 127 mm, calculated by dividing the 180 mm wheelbase by √2:



## 2. Propeller protection + base design

In the next step I drew the propellers with protection, which are 4 mm thick and will be 10 mm tall, so that it will hopefully be much safer, and because it’ll fly autonomously. For the base (the most important part for me ):

> For the main base (the red part), I chose an octagon shape because it fits the design perfectly. I drew lines that go straight through the center of each motor, and the corners of the red base sit exactly on these lines. By using an octagon instead of a simple square, I can cut away the extra corners to save weight. It also gives me flat sides to attach the arms easily and creates a clean space in the middle for all my electronics.

Additionally, I also added small squares on the ends of the octagon: the camera and servo (left) and (right) the battery.



## 3. Motor arm design

Then I also planned the arms for the motors:  
I made them come in a 90-degree angle from the straight base that connects normally like every other drone, but I also added a second arm for every motor that is at a 45-degree angle from the first arm, for more stability and less vibrations during flight. I also tried to pay attention not to design the arms too thick, so that the air can flow nicely and without problems through the propellers, so I kept them at a thickness of 7 mm.

## 4. PCB and electronics layout

Now I was mostly finished with the main design and then I thought about the PCB.  
Here is a basic schematic of all the parts assembly and the position of the PCB:



But then I encountered a problem: there wasn’t enough place for the FC and Raspberry Pi. But after googling and thinking, I came up with the idea that I could stack the Raspberry Pi over the FC to save space.  
But even after that I would have problems with routing, because the Raspberry Pi (which I would connect over GPIO pins (male/female)) would block most of the PCB because it would go from one side to the other, so I decided to only use GPIO pins for the signals I really need.

Position of the Raspberry Pi and FC:



I also thought about the problem that the battery would be too far back and the center of gravity would be off, but then I had the idea that the battery could be mounted upright (vertical), and that should minimize the problem.

---
Overall happy with the progress! Tomorrow I’ll really start with the 3D design / PCB and I’m excited to continue (I had problems connecting Lapse with Fallout so if I didn’t find another solution, check here: https://lapse.hackclub.com/timelapse/HnbnaB-3Kzma ~1.3h)

### Recording Links

- https://public.lapse-hackclub.link/timelapses/HnbnaB-3Kzma/timelapse-HnbnaB-3Kzma.mp4

## Entry 4
- ID: 3943
- Author: Stefanos
- Created At: 2026-04-25T22:08:52Z

### Content

### 25. April: CAD the motor base and arm!

Firstly, I started with the 2D design and “copying” the motor sizes, holes, etc. At first I struggled finding the diameter tool and also understanding the motor sketch, especially with the 4× M2 holes. That confused me because I thought the 1.5 mm was the diameter of the holes, but it was actually the radius.

Then I made another mistake: I thought the 1.5 mm radius was for the holes, but it was actually for the outline. For the hole size I had to search it up on the internet, which was M2 (about 1.5 mm diameter). I also had to pay attention to a recess in the middle of the motor (the side where it will be mounted), so I had to cut out a small hole with a diameter of about 4 mm.




After that I continued with the 3D design. I extruded the platform to 5 mm for stability, but not more, to save weight.

  

I also thought about making the plate a bit bigger than the motor itself, so I added about 5 mm around it for more stability and so the arms can connect better to the motor platform.

Then I remembered that I should include about 0.2 mm tolerance, so I updated the design for that.

After that I checked the screw length. The holes have a depth of about 1.5 mm and the plate is 5 mm thick (total ~6.5 mm). The screw head also takes about 1.5 mm (hidden in the platform), so I calculated:

7.5 mm − 1.5 mm = 6 mm

So I will use M2 6 mm screws, which luckily exist.

At the end I extruded all the holes, so it looked like this:


After that I started with the “2 arms per motor” design.

First, I checked where the cable from the motor comes out, because the cable should go through the 45° angled arm that goes directly to the center.

  


I made the arm go exactly 44 mm from the center of the motor, based on my previous planning. For the width I used 6 mm, and for the height I used the same as the base: 5 mm.



Then I also rounded the edges between the arm and the motor base:



Happy with today’s progress. I learned a lot in CAD design and I like the arm design for the motor. Tomorrow I will continue with the cable channel in the arm and then the main base of the drone!!! Pretty excited!

### Recording Links

- https://lookout.hackclub.com/api/media/5584e5fc-6911-425c-9b65-d1d5dc9f0595/video.mp4

## Entry 5
- ID: 4111
- Author: Stefanos
- Created At: 2026-04-26T20:03:32Z

### Content

### 26. April: Finished the Motor-Arm CAD design!

1. I started with the cable canal, but I wasn’t sure if I should use a lid or just leave it open. I decided to first leave it open and not design a lid because it would be pretty complicated, increase the weight, and make debugging or modifying the drone harder.

While starting to design the tunnel in the 2D sketch, I noticed a mistake: I saw that the ends of the arms were rounded by mistake.



So I added corners for better next design.

After fixing this, I draw the tunnel which is 3 mm width, because the cable is 2.4 mm.



Then I extruded the canal by 3 mm so that the cables can perfectly fit:



But it didn’t look clean, so for better cable handling I rounded the corners / sides:
- the back line I added a 3 mm fillet  
- the side parts I added a 1 mm fillet  



Then I continued: I started designing a small part that extrudes from the end of the 2 arms so that I can put an M2 heat insert in it and later screw it onto the base for more stability. But because I didn’t really have a clear plan where everything should be / look like and how all sizes should fit, I first started with a design of how the arm connects to the base and how the PCB and other parts should be positioned.


After I had a plan, I decided to make the height exactly 3 mm because the insert is the same size. I also made it 10 mm long for more stability so the screw has enough space, but also the cable can go into the base without any problems.



After that I also rounded the corners (2 mm) and extruded the hole for the insert, then I copied and redesigned this part on the other arm.



Lastly, I also added an extra height of 0.1 mm to the whole arm to compensate for small errors, for example from the insert.

This session today was nice and I managed to finish the arms! I am happy with the design! In the next session I will start with the base (hopefully also today!).

### Recording Links

- https://lookout.hackclub.com/api/media/eadea0cb-7eba-4867-9160-201d867545b6/video.mp4

## Entry 6
- ID: 4655
- Author: Stefanos
- Created At: 2026-04-30T18:22:41Z

### Content

### 30. April: Designing the base of the drone!!

Firstly, I created the base file where the main base of the drone should be. But before I started designing, I wasn’t sure if the center of gravity would actually be in the middle. So I wanted to calculate everything first to avoid any problems later.

The problem was that I didn’t really know how to do that, but after a bit of googling I found this:
https://www.wikihow.com/Calculate-Center-of-Gravity

For calculating the center of gravity you need the position of each part relative to the center and its weight. So I found all values by measuring distances and looking up the weights online:

- Raspberry Pi: +1 cm, 10 g → +10  
- Camera: +10 cm, 15 g (took a while to figure out)  
- Servo: 7.7 cm, 9 g  
- Battery: 76 g, -5 cm  
- FC is directly in the middle → no effect  
- all other parts are symmetric (motors etc.)

> Calc:
> 10 + 150 + 69.3 − 380 = −150.7  
> Total weight:
> 10 + 9 + 76 + 15 = 110 g  
> Center of gravity:
> −150.7 / 110 = −1.37 ≈ −1.4 cm  

This is not good because the center of gravity should be at 0 cm. So I had a few ideas:
- add weight at the front (about 9 cm in the front)  
- increase infill in the front area to add “hidden weight”  

After that I started designing:

I first made a circle based on my previous drawing. The distance was 2.3 mm, and I scaled it up 4x (to become a diameter and for the sscale 1:2), so I got 9.2 mm diameter.



Then I draw the edges where the arms connect to the base at 45° and 4.6 cm length.



But then I wasn’t sure how big the connection area for the arms should be. So I measured the arm width (6 mm) and multiplied it by 3, which returned 18 mm. From the center that meant about 6 cm spacing on both sides.

While doing that I realized I had made a mistake with some values:
- I accidentally wrote 4.8 mm instead of the correct value 48mm...

So I had to fix and update all doistances… T-T

After fixing everything, I added the final connection lines for the arms:



And finally connected everything:



Afterwards, I started designing the rectangle where the camera and servo will sit, and where the second arm connects with the base. For that I first checked my drawing to get the correct scale. In my sketch it was 30 mm, so in real size (1:2 scale) it became 60 mm, and the width was 17 mm → 34 mm in real.

So I created a rectangle with those values:



But then I got confused because the rectangle didn’t match my original sketch. I kept checking the measurements, but it still didn’t fit . At that point, I realized that my sketch wasn’t very accurate.

So I decided to first draw the motor positions and propeller radius to understand where everything actually is positioned and where everything should be:



Then I saw that the diagonal arm connections actually matched the larger circles in my sketch, and the smaller ones were the propellers. But the vertical arms didn’t fit properly, so I had to fix the layout.

So I updated the box size to 39 mm and kept the length at 60 mm:



After that I started designing the bottom box for the battery. To help fine tuning the center of gravity later, I increased the length by 5mm (from 40mm to 45mm) so I can shift the battery if needed.

So the design looked like this:



Then I exited the sketch and wanted to extrude the base, but I wasn’t sure how thick it should be. Then I remembered I still need the mounting system for the motor arms, so I checked the screw sizes.

At first I couldn’t find any of that in my notes, so I had to google again and realized there are SOOO MANY different screw types. But after searching, I decided to use ultra thin low head M2×6 mm screws because they allow a thinner and cleaner design.

The screw head is about 0.8 mm thick, so I added 1 mm sothat the screw head can hid in that. Together with the 3 mm arm and base structure, everything fits:
3 + 3 + 1 − 1 = 6 => M2×6 mm screws

Next I cut the screw holes. I first marked the center lines, extruded 5 mm into the base, and created 2 mm holes. Because of 3D printing error, I increased them to 2.2 mm.

At first I thought the holes didn’t match the arm holes, but then I realized:
one is for the heat insert, the other one is for the screw,  so everything was actually fine...



Lastly, I extruded the holes and added an extra hole so the screw heads can sit inside the base:



Happy with the progress today. I solved a lot of problems and started the base design. Next journal will be about the attachment mechanism for the arms and base.

### Recording Links

- https://lookout.hackclub.com/api/media/5f0e2622-11b6-4270-88bf-668afe9c8a60/video.mp4

## Entry 7
- ID: 4731
- Author: Stefanos
- Created At: 2026-05-01T08:48:43Z

### Content

### 1 March: Finishing the arm holders and a TON of problems!

I had the idea to move the thing where the heat insert is placed (to hold the screws and the arm on the base) a bit higher, so that the arms wouldn’t be so high and the drone would look cleaner.

But while starting, I recognized that the holes for the screws on the base were 1mm offset (they were 5mm from the edge), so I moved them to 4mm. While doing that, I accidentally deleted the holes for the screw head T-T, but I could fix that pretty quickly.

And after moving it up, it looked like this:  


And I also added that for the second arm.

But then I also added a slope for better grip and stability

After that, I decided to also add a slope on the underside of the arm. Here’s how it looks now:  


And here is how it would look then:  


I decided to use the slope for more stability, but also so that the drone looks better and cleaner.

After adding the slope, it looked like that:  


But I wasn’t completely happy, because the line where the slope ended was very back, so it didn’t look very clean:  


But after fixing and moving the slope a bit more forward, it looked much better and really nice:  


Now, after I fixed and implemented the slope for the arm and moved the heat insert part higher, I continued with the cable tunnel because now the insert part is higher and the cable has now nowhere to go through:



So I extruded the cable tunnel for 3.3 mm and rounded the edges with a radius of 1 mm:  


After completely finishing the arm, I continued with the connection of the arms to the base plate of the drone.

To start adding the case where the arms could slide in, I first needed to redesign the arms on the base, which took an ENORMOUS amount of time:
- I first had to measure everything  
- design the rectangles  
- then, because I have rounded corners:  
  1. calculate how big the circles are  
  2. calculate where the circles have to be placed  
- and then draw everything together  



But then I forgot that I should add a tolerance of 0.2 mm to everything, so I had to update everything AGAIN.

So after repeating everything 4 times for the sloped arms, I had this result:  


After that, I had to outline the parts, which was a challenge, but fortunately I managed it:  


And again reconstructed that for all 4:  


And lastly, after all this work (which was really suffering), I extruded the parts for 3.3 mm because the arm part is 3.1 mm tall and I wanted some buffer for the screw and heat insert.

After that, I also rounded the base with a radius of 4 mm:  


---

After the first part of this session, I started with the vertical arm holders.

For that, I first drew again the radius of where the arms and motors are located to know the exact positions:  


Then I marked where and how the arms are located to start again with the case for the arms:  


Then I drew the screw holes for the second arms with a diameter of 2.2mm (0.2 tolerance):  


And extruded them to -5 mm to create the holes:  


Then I proceeded like before with sketching the arm outline case:  


And also recreated it for all 4:  


After extruding them again for 3.3mm, I saw a missing part, but I quickly redrew and extruded it:  


Then I noticed that I forgot to make the holes for the screw head on the other side:  


Then I thought I was finished… but had AGAIN a problem:
the holes didn’t fit perfectly because the centers were different (4mm at the base and 5mm the arm), so I fixed that.

Before:  


After:  


It worked, but somehow other holes disappeared again, so I had to redo them.

Then another problem: one part didn’t extrude:  


So I fixed the borders and extruded again:  


Then AGAIN I thought I was done… but the distance didn’t match (on the base it was 9.5mm but the arm was 10mm):  


After fixing the lines, everything finally aligned perfectly:  


After repeating that for all arms and fixing a TON of extrusion bugs, it finally looked like this and everything fits perfectly!!!  




P.S. While writing this journal, I had a mini heart attack because the images didn’t load and only showed "image.png", but after refreshing they appeared again.

Also, I learned a new Fusion skill: you can go back to old sketches and apply changes. Soooo cool!!

Exhausting session but happy with progress.

### Recording Links

- https://lookout.hackclub.com/api/media/767e64b0-7fa2-45ec-92db-6d659050f224/video.mp4
- https://lookout.hackclub.com/api/media/1597db2d-4a67-44e4-9acd-be2e7ee1701c/video.mp4

## Entry 8
- ID: 4783
- Author: Stefanos
- Created At: 2026-05-01T16:17:49Z

### Content

### 1 May: Adding the combiner for the wall part and designing the small wall on the platform

In this session I wanted to make the connection between the base and the wall, because I plan that the main case (where the drone is connected with the arms) will be in 3 parts: the platform, the walls and the top dil

So in this session I focused on making the walls as a separate part.  
My plan is to have 3 main parts in the end: the base with the bottom plate, middle walls and the top cover.


I want to connect the wall and the platform, like all other parts, with M2 screws and M2 heat inserts.

After starting the design, I wasn’t really sure where the inserts and screw holes should be placed, because in the front it’s mostly open and the camera takes a lot of space and has to rotate.  
So I first made a drawing and planned where everything should go, and decided to use this:


Afterwards, I sketched where the screws should be and tried to figure out how to position them so they use as little space as possible:


Next, I drew the hole for the screw itself and its head to check where it can be placed so it doesn’t collide with anything or doesn´t look good. I also had to consider the screw head hole on the other side:


After finding a good position, I applied it to all four corners:


Then I cleaned up the sketch so it would be easier to check and extrude later:


I also changed the wall thickness from 2.5 mm to 2 mm because that should still be stable enough and saves weight:


After that, I added a 2 mm outline to all sides of the platform (except the front, because it will probably stay open due to the camerarotation).  
I also discovered that there is a tool for the outline, which I didn’t know before!!! That would have been SOOO useful in the last session



Next, I continued with designing the mounting hole between the platform and the wall at the back (where the battery will be):

1. I found the center to align the hole  
2. I drew the screw hole (2.2 mm) and the screw head hole (4.3 mm, 1 mm depth)



But the distance to the edge was too small, so I added +1 mm.

Then I noticed that the 4 corner holes were also WAY too close to the edge (only 0.3 mm), so I increased that as well:


Then I added tangents from the screw head circle at 45° into the edge, so I can later split the platform and wall and still have a strong connection.  
(actually, I made all connections with 45° angles for better grip and stability.)


Then I worked on the front connectors (where the camera and servo will be). Here I had to be VERY careful to leave enough space for the rotating camera.
I started by drawing two circles and kept a distance of 3.15 mm from the edge and from the arm holder. Then I added tangents and parallel lines so I can later split wall and platform cleanly:


Then I built that on the other side aswell:


So in the end it looked like this:


But then I realized the inserts need thicker walls, otherwise they might break.  
So I modified the 4 corner connectors and made them stronger:

and again, I made that for every of the 4

After designed the fist I applied that to the other 4.

Then I also improved the back connection by making the outer circle bigger and moving the hole deeper into the platform:


After modifying it, it looked like this:


Then I realized I forgot to add a 0.2 mm tolerance between platform and wall (again), so I fixed that and extruded everything to 3.3 mm:


And finally it looked like this:


After cutting the screw holes and screw head holes, I got this beaufully piece:



P.S. I noticed I wrote "1 March" in the last journal, that should be May, sorry ;)

Happy with the progress. Next session will be about the walls. Pretty excited!!

### Recording Links

- https://lookout.hackclub.com/api/media/1f9980de-f783-43fc-88d0-abf6451be263/video.mp4

## Entry 9
- ID: 5082
- Author: Stefanos
- Created At: 2026-05-02T08:45:23Z

### Content

### 2. May: Designing the connection to the walls and designing them!!!

First, I inserted the sketch (using Insert Derive, a new feature that I learned) with the combination sketch from the platform and the walls. Then I projected the important parts (here only the connections) to a new sketch so that I can redesign them. I also learned the tool to project points, lines, and bodies, sooo cool!

And after doing that it looked like that:


Afterwards I added a tolerance on all sides (where I haven't already applied one) of 0.2 mm so that everything will fit perfectly:


For the beginning, I extruded them to the height of the connector, so 3.3 mm, but I will probably have to adjust that in the future (and I forgot to say I also added a tolerance of 0.05 mm):


Then I continued making the holes for the heat inserts:

1. I again projected the center points of the connectors to draw the circles  
2. Luckily I knew which diameter I should use for the heat insert holes: 3.3 mm, because I already did that for the arm holder heat insert holes, so I just copied that value  
3. Then I drew the circles with the projected points as centers  



Then I proceeded with extruding them:

I extruded them 3mm + 1mm in height because the insert has a height of 3mm and needs 1mm buffer for optimal grip (thanks Google). And added additionally 4mm for more strength! 

But during that, I encountered a problem: the extruded connectors were only 3.3 mm high, while the holes were 4 mm.

So it looked like that after extruding. The only problem was that I extruded the holders only to 3.3 mm and the holes to 4 mm. That’s why I had to go back to the beginning (T-T) and extrude them more so that they properly contain the holes:


But after repairing and redesigning everything, it looked like that:


After all this progress, I wanted to properly see how everything looks assembled, so I:

1. Created a new file called “All-together”  
2. Then I had to google how to combine or insert everything into one file, because I first thought you just copy the parts (completely wrong). I found out about the feature “Insert Derive” which lets you insert bodies, sketches, etc. into another file and it updates automatically if you change the original file  
3. Then I inserted the base file and the walls, which were perfectly aligned already, so I didn’t have to move them. But the arms were a pain: I had to move them manually and align them perfectly. Then, because I didn’t know about the mirror tool at first (which would have saved me sooo much time before T-T), I copied one arm again. After that I found the mirror tool and mirrored them along the Y-axis  
4. I also organized the bodies folder by creating two subfolders called “walls” and “arms” so I can work more cleanly  

Then after doing all that, I saw the drone fully assembled for the first time  and it was ABSOLUTELY FANTASTIC!!!

To continue, I inserted the sketch from the walls and projected it to a new sketch so that I can modify it independently from the other parts:


Then I redrew the walls and also extended them over the arm connectors so that there are no holes and everything is nicely connected:


After selecting all the wall parts, I extruded them to 8 mm as a new body, so I can later cut the bottom part because otherwise it would collide with the base:


The problem during cutting was that I couldn’t find a cutting tool, but I discovered that you can extrude and enable “cut mode” and that worked perfectly (cut for 3.3 + 0.1 mm tolerance):


After saving that file and updating the All-together file, it looked like that (almost perfect):


But there was a small detail that didn’t look nice and made the CAD unclean:


To remove this small wall cut , I went back to the sketch and drew the missing part by making a +0.2 mm outline. That fixed the problem, and after extruding it looked clean again:


I was almost finished, but there were a huge number of edges and corners, so I decided (for better look and better 3D printing) to round them all.

I mostly chose the rounding radius by feeling (look + space saving), and after doing that it looked like this:


A positive side effect of rounding was also that I gained more space for the PCB.

And lastly I updated the All-together file again, and now the drone looks like this (amazing, jippy!!):


VERY happy with the progress today, because I was really afraid of starting with the wall connections since I didn’t really know how to design them, but in the end I got this!!

### Recording Links

- https://lookout.hackclub.com/api/media/24cd763d-6736-4204-b814-cc2be1a67d77/video.mp4
- https://lookout.hackclub.com/api/media/8c2a5f22-0b6b-4388-be14-7067c33dfd82/video.mp4

## Entry 10
- ID: 5152
- Author: Stefanos
- Created At: 2026-05-02T17:59:32Z

### Content

### 2. May: Finished the Main CAD design on the drone!!!
At the beginning, I firstly saw that the cable flow/canal wasn’t perfect and big enough because there was about 1 mm space for the cable, which isn’t really good (and enough):


So I had 2 ideas on how to fix the problem:
1. Complete the bridge over the connector but make a half-circle cutout to make the cable flow bigger  
> would look like that  
> 

2. Or make it from the inner side of the drone (at this part oblique), so that I can gain another 1 mm and from the outside it would look completely normal  

btw, my goal was to get a "tunnel" of 2–3 mm, not 1 mm like now  

So I firstly tried the 2nd option because I liked it more:  
1. Measured exactly where the connector begins and ends so that I know where the oblique should be, and got these values  


2. After knowing where everything fits and all values, I created a new sketch and started drawing the distances  


But when I started to make the oblique, it became a horror!  
Because I didn’t know how to create an oblique, I googled and saw that you can deselect tangent chain, then just mark your line and it would work. But I had the problem that the whole line was connected with the curving tool, which was very annoying. After like 10 minutes of trying, I gave up and searched for another way to make it. I saw that you could split the thing into 2 bodies and completely separate the lines, but for some reason that didn’t work either. So I gave up on the oblique and continued with the half circle:

Because I had all values, it was pretty easy and I just had to find the center of the line of the circle and made a circle so that it looked like that:  


But I wasn’t completely happy with this because it was too big and didn’t give the arm support for stability. So my plan was to make the circle thinner so that it does have friction with the arm, so that it isn very stable. So I wanted to make it thinner like this:  


So after measuring the new distances and drawing the new circle and cutting it out, it looked like that, which is much better:  




But then I noticed that I had added a small tolerance between the wall and the platform, which is for the grip and stability not the best, so I removed it and then it looked like that:  


And after everything was fine, I applied the holes to all other 4 corners:  


---
Next I wanted to continue with the walls, but I couldn’t just extrude the base right now because there are also the connectors, and if I extruded it, I would also extrude the connectors.

So I had to first create a new sketch on the walls, project the original walls, fill gaps, and then make an outline of 2 mm:  


After that I could extrude the walls, but I had to think about the height of the drone, so I looked up how tall the parts will be. The tallest parts were (camera and battery) (in my opinion before I searched it up):
- for the camera I couldn’t find any dimensions, but it seems small like 2–3 cm, and the battery is 22 mm high, so I decided to make the drone 40 mm high so that everything fits for sure and I have some buffer and also space to add later stylistic accents  

But after looking at the drone in All-together, it looked pretty chunky...  


So I then tried adding only 30 mm, which looks much better:  


After the walls were standing, I wanted to focus on rounding the connector to save weight, material, and space, and so that the 3D printer can print the parts more easily, faster, and without errors.

But I didn’t want to use the rounding tool because if I print the parts upside down, it’ll need many supports and would be harder to print. So I decided to use straight corners that kinda round the connector. For that reason, I searched online and found the perfect tool/feature from Autodesk Fusion for that: chamfer, which makes edges, and this is perfect for my case.

So I directly applied that and this is:

before  
  
after:  


---

After the walls were firstly finished, I continued with the case of the drone.

Therefore, I started by creating a new file called "cover" and inserted by derive the sketch of the walls of the wall part:  


After projecting and drawing all missing parts of the walls, I outlined the inner wall edge by 0.3 mm per side and extruded the whole cover by 5 mm:  


Then I wanted to add a bit of an oblique to the cover because I saw in a very good video that it is helpful (https://www.youtube.com/watch?v=XKrDUnZCmQQ). If the cover originally doesn’t fit because of 3D printing, in that case you can add an oblique so that it at least fits a bit.

So after searching, I found out that the best solution for the oblique would be to use the draft method. So I tried implementing it and it worked on the first try!!! I made it go down by 10°, and after that it looked like this:  


I also decided to remove the inner part of the cover to gain more space, lose weight, and get more flexibility if it doesn’t fit very well. I decided to leave an edge of 2 mm and a depth of 1 mm (because on the top comes again 3 mm).

So I began with the removing. Like I said before, I left 2 mm width and it looked like that:  


And now I had to design the thing that holds the cover because now it would just drop into the box. I decided to make it only 3 mm height because it’s stable enough, looks the best, isn’t too big, and has the least weight. After projecting and drawing again the lines, it looked like that:  


And then, like I said before, I extruded everything by 3 mm:  


Lastly, I also attached the cover into the All-together to see the final result:  


Overall, very happy because I finished the main drone CAD and now only have to design the holder for the servo + cam, the PCB holder, the sensor holder, and the pogo pins holder, but that will happen later (excited for the servo, although it’ll be very hard). Oh, and the wind guards (very important), almost forgot.

### Recording Links

- https://lookout.hackclub.com/api/media/def8403b-72f5-4a88-9f0d-cbc23318e899/video.mp4

## Entry 11
- ID: 5483
- Author: Stefanos
- Created At: 2026-05-04T20:31:08Z

### Content

### 3 May: Building the camera and servo mechanism

**FOR CLEARANCE!!!**: I accidentally left the recording running while printing and measuring one part. It begins from there on where the screen is black! Please **DO NOT** count these hours. I do not want to get banned (so I think the last 30 minutes were not stopped, so don’t count them).

Today I wanted to make the servo camera stand rotating thing, so that I could finish the main CAD.

To start, I searched for the camera size and where all the holes are positioned.

But after going to the AliExpress page of the camera I’m going to buy,

I quickly realized the problem: there were NO sizes of the camera. So I decided to search the camera on other sites, but I couldn’t find the exact product. After finding the manufacturer, I found some more products from other sellers, but again: NO DIMENSIONS

So I decided to take the dimensions of another camera that had dimensions and decided to draw the holes for the camera, then when I bought the cam. But now I will just design the plate and the holes later in the build phase.  
The size of the camera is 24×25 mm.

So I first made a drawing to test and make a plan. I decided to make an arm that connects to the holder of the cam and can be rotated via the servo, so that the camera can look to the front but also down.


Then, after drawing, I searched for the dimensions of the servo motor to start with the design of the servo motor holder.

And then I found a perfect sketch of all sizes:


But then I planned the thing I was the most afraid of: the camera holder and connector to the servo:

But before I continued, I thought about the servo-to-arm holder connector, because I remembered that I once (3 years ago) built one of these, but they broke very easily and I had to glue them together, etc.
WhatsApp Image 2026-05-02 at 22.22.46.jpeg

But I think the problem was that the part around the servo rotator was too thin, so I didn’t have enough place to get grip on it, and also it was too thin, so it broke. So this time I’ll try to build that bigger and also more stable. 

But because I firstly didn’t know that my printer could print the rotator which is clipped on the servo, because there were tiny components of 0.1 mm, I sadly decided to design a part around it and glue it with super glue and then connect it to the arm/cam...

---

So after clearing everything, I started with the 3D design. I decided to start with the servo motor holding case.

Therefore, I created a new file called "servo_holder" to design the holder of the servo motor first.

Then I continued by making a first draft sketch of how big the servo is and drew all the sizes from the side view.


After that, I added a tolerance of 0.2 mm to every side so that it would fit well, and then I also made a bigger hole on the lower left side of the holder, which has a radius of 4.5 mm, to make sure the cable can go through it.

On the bottom left corner, I also made a hole because I saw in a previous video that if you make holes in the corner, the parts that have to fit in the case can fit better and with a higher percentage.

And lastly, I also rounded the corners to optimize the 3D process.


After that, I also extruded the whole thing (bottom) by 1 mm, then the walls, where the servo motor will sit for 12 mm, and then an additional 3 mm on the top.

But because the servo is completely still and doesn’t move, I thought of this:

To connect the servo to the connector, I had to screw in the screws that are delivered with the servo directly into the 3D-printed material. I directly tried that out on the holes of some older benchies:


And then I found out that the best diameter for the hole was 1.5 mm, so I went to the next step:

After searching the positions of the holes on the 3D model and applying them to the 3D model with a tolerance of 0.2 mm, it looked like this:



And after that, I rounded the corners of the 3D model:


After all that, I also added the bottom and the top, so that the servomotor is perfectly covered and clean.

For the bottom, I first made it only 1 mm, because the height would be experimented with because of the rotation of the camera.

- I started by creating a sketch on the underside of the connector, projecting the essential points and lines and drawing over the gaps.


After that, I exactly did that on the top/cover:


And after all this, this part was finished (just on the top 3 mm).

---

After finishing the servo holder, I continued on the servo connector with the camera holder.

And then I thought of another idea because I did not like the idea with the glue:

I found a 3D model of the horn and printed it quickly to see how good it would be (it took only 3 minutes to print, yippe!!!).

During the print, there were many crispy sounds, so the filament is very wet. I need to dry it later in the build phase (btw it’s currently 0:15 am T-T).

Some insight of the print :3



..., and it fitted PERFECT!!!

Next, I started by importing the 3D model so that I could then take the parts that I needed and design the camera holder.


After importing, I saw that the model did not have any sketches, so I couldn’t use it. But luckily, after finding the designer again, he showed all the important instances:


So I started designing:

I started with the circles, which were very easy to design:


(Btw my lookout is crashing ALL THE TIME and it didn’t record for some reason for some minutes, the 2nd monitors where I am writing this. Not sure what it missed, but FYI I searched up again, like I said before, the 3D thing and the website and wrote that during this time.)

But then I had to think about how to make those teeth, because I didn’t want to do everything manually.

So, after searching online for the best way to make this, I found out that I first had to create one tooth manually and then there is a feature called circular pattern that can create the others. So I started by creating only one first:


And after that, I opened the circular pattern tool, selected the tooth and then the middle points of the circle, counted on the reference how many there are (21), typed that into the settings of the pattern tool, and... FIRST TRY!!!! It worked.


Amazing!!! Next, I drew the holes around the teeth so that there is a wall, and I also did that with 1.5 mm for best stability:


After that, I extruded everything for 2.5 mm because that part of the servo is about 2.5 mm.


Then, after that, I added the separation so that you can screw the holder to the servo with a screw and the screw really holds the connector to the servo and puts pressure on it.


And lastly, I extruded the walls again, so that in the end it looked like this:


Then I made the arm that goes from the connector to the camera and made it exactly 20 mm long because it is the closest possible distance from the arm that does not hit the servo, and the servo has to be 20 mm above the ground so that the camera can rotate perfectly under the drone without making it look unclean. And I made the thickness 5 mm like the whole connector, so that it looked like this:


But then I wasn’t sure how to position the plate that holds the camera onto the arm:
- Should the arm connect to the middle of the plate, the top, or the bottom?

And I asked myself so many of these questions!!!

But in the end, I decided to make it in the middle first because it is the most reliable and you can calculate more easily where the camera will be. But the 3D print would be bad because it had to print the teeth upwards, and this would cause bad grip, so I decided first to make it from the top. But then I thought that the servo had to be 20 mm up in the air, and if the camera is about 25 mm high, then the camera would be over the drone, which would look horrible. So I decided to calculate roughly: the camera is 20 mm high, but the camera has to be in the middle, so 25 mm - 20 mm = 5 mm. The connector should connect from the top 5 mm down, so something like that:



After drawing the camera holder with the dimensions of 24×25 mm, it looked like this:


And I extruded that for 1.5 mm.

Then I saw that I built the direction from the camera holder wrong (the servo connector had to be rotated 90 degrees to the left T-T).

So after deleting and turning everything, I drew it again and it looked like this:


After that, I wanted to print that part, so I exported it and printed it out...

And after testing it out, they were PERFECT!!!!!
WhatsApp Image 2026-05-03 at 14.13.46.jpeg

Next, I want to combine both parts and add them to the base:
So, I
1. opened the base file again and measured the middle to first see where the camera would be positioned
2. drew where the camera will be (the camera is about 25 mm wide)


And after measuring how long the arm to the center exactly is, to see where the servo should be positioned, it was 21.5 mm. But I also have to add 1.5 mm for the thickness of the camera platform.

> So together it is 21.5 + 1.5 = 23 mm

I also wanted to bring everything about 2 mm more back because the camera is pretty chunky and I do not want it to be completely outside.

> So in total it is 23 mm + 2 mm = 25 mm

So after I drew the middle points of the servo gear:


But then I realized that I was extremely dumb and that, how I designed it, it would not fit:


So after measuring how much space I had on that thing and on the inner sides (inner wall to inner wall I only had 35 mm, which is very small because the servo itself is 30 mm),

But to fix that problem I had 3 ideas:

1. make the servo connector/arm thinner  
   >   
   would save me 1.5 mm, and then I would also need to remove the back side of the servo motor holder  
   > 

2. I had to remove the back wall of the servo holder to save 5 mm, and that would mostly solve the problem.

3. If I would implement that, I would only have a width of 32 mm, but then the whole servo construction would still be outside the case. If I want the camera to be in the middle, then I also have to change the arm of the camera holding module so that the servo can be at the center.

So, I started by removing the back of the servo holder.


After I drew the servomotor and the camera, I tried multiple positions, like the distances to the walls of the servo when it is connected to the connector with the arm, how far away it should be, where I also had to pay attention to the motor arm connector being higher than them and also higher than the platform-wall connectors, and lastly I also drew how the arms should be designed to hold the camera:

And so it all locked then together:


And after that, I inserted the servo holder into the file to position it right.

After I positioned it, I wanted to import a servo 3D model to see if it was fine.



And after adding the servo into the servo holder, I saw that it didn’t fit perfectly, and after I also checked it with mine, it also didn’t fit perfectly. So I quickly fixed the values.

And then I had to recreate the servo motor arm/connector with the sketch I did previously, and then it looked like this:



After rounding like that:


And after combining:


Then I wanted to see if the rotation would be fine. That’s why I searched up how it works, and you could have done that with joints, which I wanted to do, but I first did not find the joints and then it also didn’t work, so I ended up just using the move copy tool.

But after it worked and I tried it, it was (after rotating) inside the connector for platform and wall and the arm connectors:


But then I thought for almost 30 minutes about how to solve this and thought: should the camera be inside the case, or can it also exit it for better compatibility? But what happens with the cable and where does it go? And if I let the camera go outside the frame, where will the cable go? And on and on and on...

So I decided to take a short break and go outside, and while doing that I had (firstly) a BRILLIANT idea!!!

- I could just connect the arm that connects the servo and the camera, and not at the top with the camera frame, but on the bottom, so that the camera does not go that far back when rotating. And after measuring it, it  works perfectly.

But I still had some issues:

1. The connector from the walls to the platform was blocking the camera arm and the camera itself



> Solution: after a bit of thinking I had the idea to just curve the arm a bit earlier and deeper in the middle, and also cut a bit of material at the connector and make the camera arm a bit shorter, so that the whole construction can go further in the front.

2. I didn’t really know whether the camera should still be inside the frame or go outside, but I decided on the first option because during landing, the second option would just damage the cam.

And after finding an amazing solution, I started designing the arm of the drone again and changed what I said before.

So I started completely redesigning the arm and deleted everything except the gear in the middle:


And then started designing that:


---

BUT while doing that, I was completely shocked. I WAS SOOOO WRONG!!!! Making the arm go from the top to the bottom would NOT change the position of the camera, and then I almost cried because I worked on this mechanism for 5 hours and now everything was for the trash, and I had to almost redesign everything. But after a bit of depression time, I had a new idea:

I could just flip the servo motor 90 degrees to the right so that it does not lie on the ground (it stands upwards now), and the gear is on the bottom. Then I save a ton of place, and the height is fine, and then I wouldn’t have the problem with the camera size and motor arm connectors, because the camera would turn not completely to the back but further to the front and just be under the drone, but only by 8 mm, and that should be fine because my landing station will be about 20 mm high. So this time I really had the perfect idea:



So now I was SUPER motivated again and directly started modifying the servo holder.

I actually decided to build the motor holder again because I messed it up a bit, and I want to fix that now.  
I went through it exactly like before:

First of all, I drew the rectangles:


Then I added at the top boxes in the center holes with 1 mm diameter for the screw:


And lastly, I rounded everything for better printing:


And after positioning the base it looked like this:  
For the position, I paid attention to the center of gravity/mass position and the distance to the sides, so that the arm has enough room and is not too far away from the camera.



After placing the servo motor in the correct place, I measured where the center point of the rotating part on the servo motor was. I calculated and measured all distances so that everything would work.

And then I started designing the arm:


For the camera holder, I measured the distances for applying:


And after hours of trying, I got this:


And after all that, it looked like this:

<- fire

Happy with the progress: 7h!!! (sorry that the journal and session became so long <3, next one will be shorter) But also completely exhausted, do not want to touch that part again!!!

### Recording Links

- https://lookout.hackclub.com/api/media/95a0c005-7fa1-45bd-ac90-e32c879c7230/video.mp4
- https://lookout.hackclub.com/api/media/fd2ae5aa-daa7-4065-9fdf-1736ad547949/video.mp4

## Entry 12
- ID: 5794
- Author: Stefanos
- Created At: 2026-05-06T20:48:33Z

### Content

### 6. May: Fixing some issues with the servo motor and FINALLY finishing it!

Btw I’m currently in school and forgot my mouse, so designing will be tough with just a trackpad!

I started optimizing the servo motor sizes because after printing that part I noticed that it doesn’t fit:



SO I decided to make the holder bigger by adding an additional 1mm to every side.  
But before doing that I had to remove the roundings from the holder to better make it bigger:



After that, like I said before, I added 1mm to every side so that the parts would fit perfectly:



And after rounding again it looked like this:



Then I saved the file and updated it in the all-together file,  
but for some reason I got thousands of errors and warnings that it couldn’t update the part. After checking what happened, I saw that I accidentally didn’t save some changes. But I also found out that I had one problem:



The holder and the wall connector were colliding....

So I had the idea to cut some material so that the servo would perfectly have its place. After cutting some material it looked like this, and I only had to delete one thin thing that looked strange:



Then I had to head to my violin lesson and then back home. After doing German homework, I directly continued. (7pm now)

But for some reason it didn’t save my progress and I had to redo some steps T-T, like the rounding of the holder:



But the problem was that I was on the wrong timestep in the timeline, and after that everything was fine again...

(and then I noticed I didn’t record that T-T)

But after that I finally deleted this part that was overhanging.

And after rounding it looked like this:



So after that process I am going to continue cutting the platform because the camera needs room and a cut in the platform to go underneath the drone.

But before that I had to position the camera arm perfectly, but that TOOK A LOOOOOT OF TIME. After trying, I found the perfect spot and positioned it:



But while doing that I encountered 2 problems:  
1. The camera wasn’t perfectly centered  
2. The arm was too thick so that it almost touched the wall  

For the camera centering, I first measured both distances from the corner to the platform:  
left 2.476mm and right 4.586mm. After subtracting them and dividing by 2, I got 1.057mm that the whole thing had to move to the left. So after changing the sketch it looked like that.

But for some reason it didn’t update...

After googling, I saw that I should check if the Capture Design History is disconnected, if the link is broken, etc. But nothing worked, SOOO I decided to relink the arm and position it again, and it actually worked. It looked like this:



And after making the arm thinner it looked like this:



After that whole process I finally could cut the hole, but I wasn’t sure how to do this. After a couple of minutes of research I found out that you could use the revolve function, but it didn’t work for me, so I had to find another solution.

But after searching I checked again and understood that I was wrong, because I first thought that I had to select the whole body for that feature, but I just had to use faces. It was possible, I just forgot to apply some faces.

After finding that out I applied it, but I quickly realized that for some reason it was always shifted and not correct, which freaked me out:



And after a ton of googling I found out that the face should be at the same height as the center rotating point, otherwise the point gets shifted and, like before, it would be wrong. So I had to cut the arm in half. For that I again searched online and found out that I had to create a plane and bring it to the right height, then select the object I want to cut with this thing, and THEN IT WORKED:



After that I applied it to all sides on the inside, an outline so that everything sits perfectly:



Lastly I also deleted this part of the platform:



So that the camera thing can go through.

And after rounding the edges it looked like this:



So one problem was left and then I go to sleep: the servo motor holder is higher than the walls:



That’s why I have to make the walls 4mm higher.

Final look of today:



Happy, happy today, but it was a bit stressful with the cutting. Still happy that I managed that and excited for tomorrow!

### Recording Links

- https://lookout.hackclub.com/api/media/177c508f-c163-44e8-9c2b-65a405c1201e/video.mp4

## Entry 13
- ID: 5950
- Author: Stefanos
- Created At: 2026-05-07T20:39:42Z

### Content

### 7 May: Added the ToF-Sensors to the CAD Model and optimized it!

Today I wanted to make the holders for all 4 ToF sensors that I chose in an older journals.

But before I started doing that, I first created the meshes for the servo holder for printing the servo holder to test if now everything is fine (from the last journal).  
Therefore I first created a mesh, then opened it in the slicer, saved it to a stick, and started the print. But while the print was running I continued with the "real" part of the journal.
 
Some pics from the print :3





Then I started with the ToF sensor holders on the front, right, left, and the bottom.  
Next I continued with adding the holes for the sensors, but I wasn’t sure how to connect them and place them in the platform/wall:  
Should I make something like pins to connect them, glue them, or screw them, because they have holes?

And after a bit of searching online for solutions I found 2 typical solutions:  
1. Use normal screws  
2. Make little 3D-printed pins where you can place the sensor on it  

And I decided to use the 2nd option because it is less weight and easier to design. But therefore I had to find the sizes of the holes and the distances.  
Because I AGAIN couldn’t find the real sizes in the AliExpress store from the distance sensors. But then I found the sizes and searched for the best position for the sensor that was in front looking to the bottom, and then I first realized how BIG these sensors are. So I chose this position and drew them:



First I created a new sketch, found the center, drew the rectangles of the sensor and then the circles, made them slightly thinner, and after extruding and cutting the hole from where the sensor is looking, rounding the corners, and drafting the pins for optimal fastening, it looked like that:



Then I continued with the left and right side sensors.

And after building the holder pins and the hole for the sensor it looked like that  
(same process like before):



And then I wanted to copy that to the other side but I wasn’t sure how. But then I got the idea to just mirror the thing because it was identical, just that the holes and the pins would add to the other side.

For doing that I had to split the body into two parts so that I could mirror it and combine it.

But then I saw that I couldn’t just mirror it because that part is different from the other side, so I had to split it shortly before these parts:



So I first created a new plane, split the object that shouldn’t be mirrored, then split it in half to copy the sensor plate, and then it looked like that:



And after doing the bottom, right, and left sensors I continued with the front sensor, but there I quickly saw a problem: there wasn’t enough space for the sensor.



So I decided to move the camera plate further down so that I can get a bit more space and can position the motor above it. I also think that it will look better because then it won’t be that open anymore right now. SOO I started by measuring it and it actually would be possible to do. After measuring it should fit, but very knapp, only 1mm free between them. But I started by moving the camera plate further to the bottom (8mm).

And after I edited that it looked like this:





The next step was to make a wall above the camera for holding and placing the sensor.  
But therefore I had to remove the case holder on that spot so that I have more space for the sensors.

But to start with I switched to the cover file and made a new sketch, selected that part that I didn’t need anymore, extruded it in cut mode, and after rounding it looked like that:



Next I added this small “wall thingy” because there was too much room there and it looked unclean, so I had to change that and it was important for the next step (hope with that image it’s more recognizable):



So I first started by extruding that part in the platform and then adding the new fillet and then copying that to the other side:



And after extruding that part for 1.495mm and rounding it, it looked like that:



And after extruding the pins and making the hole (FOR THE 4th TIME now T-T) it looked like that:



And in total:



And lastly for today I wanted to find the correct pogo pins and then also make the holes for them.

But after finding the best pogo pins (decided for them because shipping is very fast, very cheap, small, and only 2 pins for charging), I will do the implementing tomorrow because I’m tired a gotta finish presentation for school...

Here’s the link btw: [https://de.aliexpress.com/item/1005006525401310.html](Pogo pins)

Happy with the progress because I’m almost completely finished with the CAD model of the drone. Tomorrow I’ll implement the pogo pins and make the landing station, and then on the weekend I’ll do the electronics!!!!! (very excited!!)

### Recording Links

- https://lookout.hackclub.com/api/media/49cf092d-5564-4cd1-9689-c9ab40cbbf67/video.mp4

## Entry 14
- ID: 6140
- Author: Stefanos
- Created At: 2026-05-08T19:09:51Z

### Content

### 8. May: Finishing the Drone CAD: adding the prop guards!

Today I wanted to make the prop guards so that I don’t cut my fingers during testing (scared).

So I started by first creating a new file for the guards.
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

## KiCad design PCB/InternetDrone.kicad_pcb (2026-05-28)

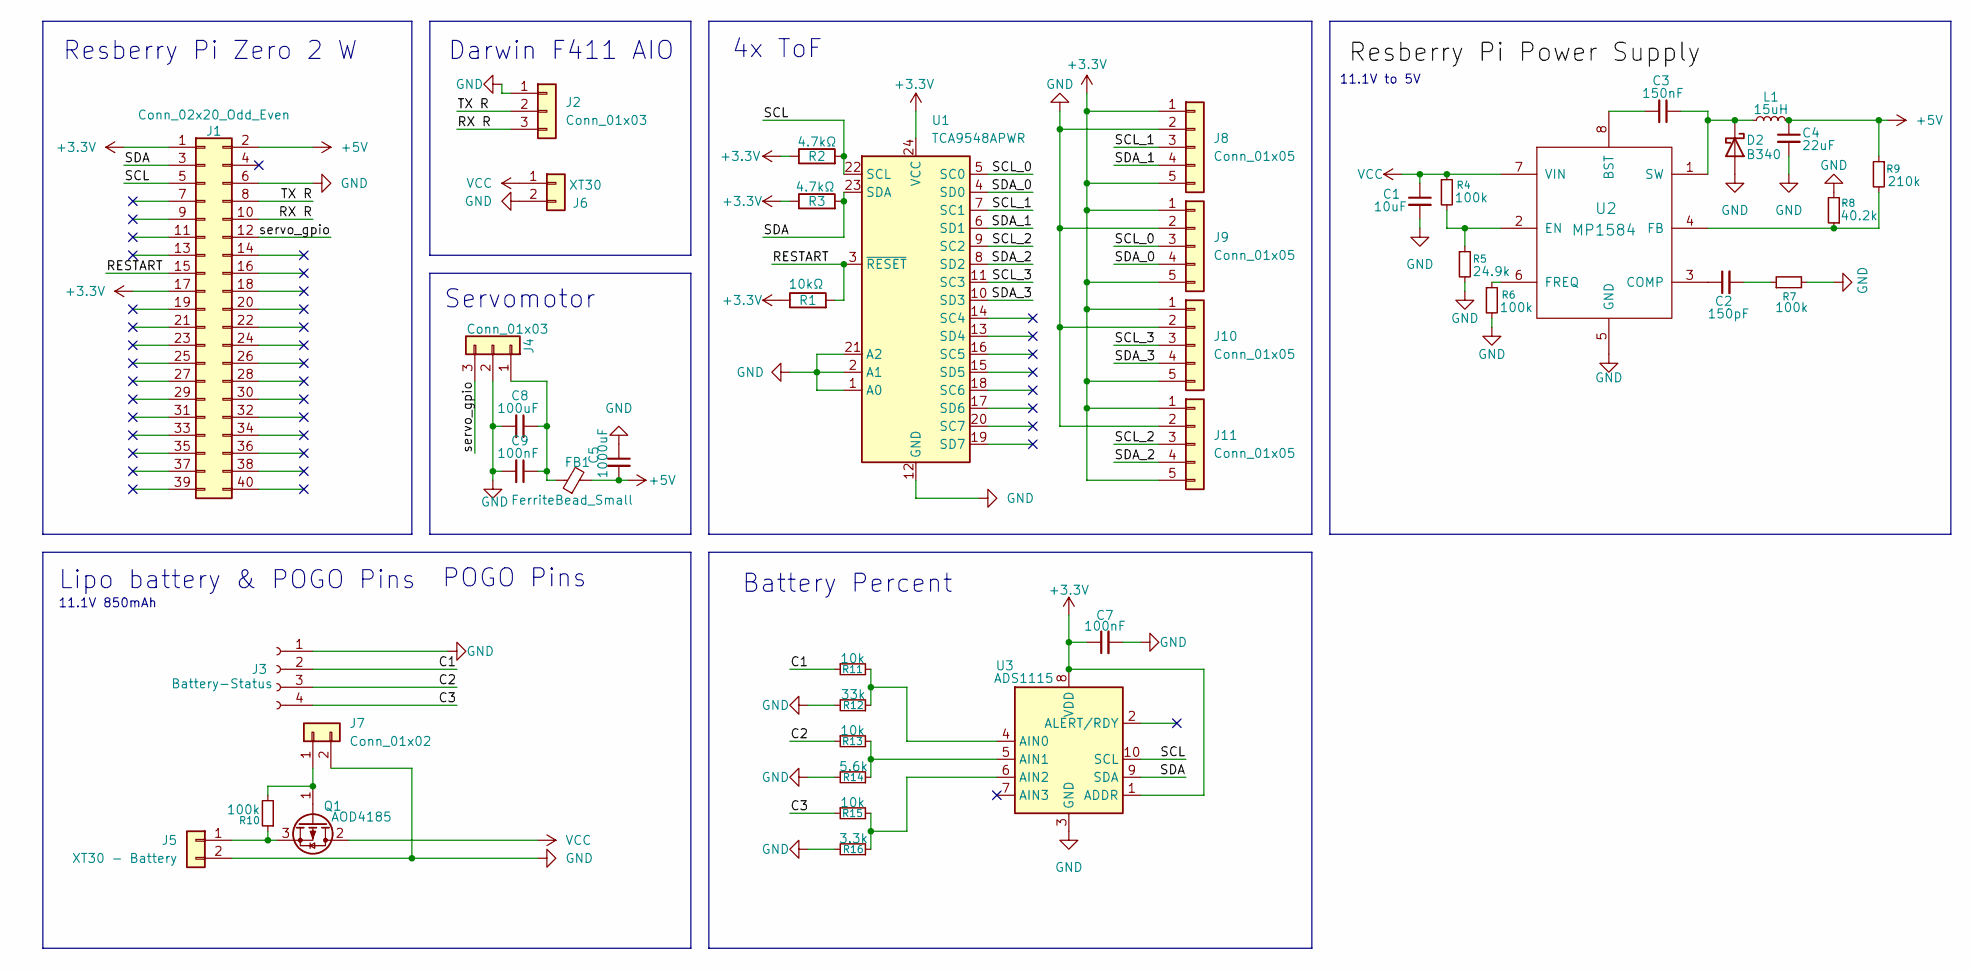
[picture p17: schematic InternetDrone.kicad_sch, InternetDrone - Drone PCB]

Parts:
C1: 10uF; C_0805_2012Metric
C2: 150pF; C_0603_1608Metric
C3: 150nF; C_0603_1608Metric
C4: 22uF; C_0805_2012Metric
C5: 1000uF; CP_Radial_D10.0mm_P5.00mm
C7: 100nF; C_0603_1608Metric
C8: 100uF; CP_Radial_D6.3mm_P2.50mm
C9: 100nF; C_0805_2012Metric
D2: B340; D_SMC
FB1: FerriteBead_Small; L_0805_2012Metric
J1: Conn_02x20_Odd_Even; PinHeader_2x20_P2.54mm_Vertical
J2: Conn_01x03; JST_GH_BM03B-GHS-TBT_1x03-1MP_P1.25mm_Vertical
J3: Battery-Status; JST_XH_B4B-XH-A_1x04_P2.50mm_Vertical
J4: Conn_01x03; JST_GH_SM03B-GHS-TB_1x03-1MP_P1.25mm_Horizontal
J5: XT30 - Battery; AMASS_XT30U-M_1x02_P5.0mm_Vertical
J6: XT30; AMASS_XT30U-M_1x02_P5.0mm_Vertical
J7: Conn_01x02; JST_GH_BM02B-GHS-TBT_1x02-1MP_P1.25mm_Vertical
J8, J9, J10: Conn_01x05; JST_GH_BM05B-GHS-TBT_1x05-1MP_P1.25mm_Vertical
J11: Conn_01x05; JST_GH_SM05B-GHS-TB_1x05-1MP_P1.25mm_Horizontal
L1: 15uH; L_7.3x7.3_H4.5
Q1: AOD4185; TO-252-2
R1: 10kΩ; R_0603_1608Metric
R2, R3: 4.7kΩ; R_0603_1608Metric
R4, R6, R7, R10: 100k; R_0603_1608Metric
R5: 24.9k; R_0603_1608Metric
R8: 40.2k; R_0603_1608Metric
R9: 210k; R_0603_1608Metric
R11, R13, R15: 10k; R_0603_1608Metric
R12: 33k; R_0603_1608Metric
R14: 5.6k; R_0603_1608Metric
R16: 3.3k; R_0603_1608Metric
U1: TCA9548APWR; TSSOP-24_4.4x7.8mm_P0.65mm
U2: MP1584; SOIC-8_3.9x4.9mm_P1.27mm
U3: ADS1115; TSSOP-10_3x3mm_P0.5mm

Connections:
+3.3V: C7.1, J1.1, J1.17, J8.1, J8.5, J9.1, J9.5, J10.1, J10.5, J11.1, J11.5, R1.1, R2.1, R3.1, U1.24 (VCC), U3.1 (ADDR), U3.8 (VDD)
+5V: C4.1, C5.2, FB1.2, J1.2, L1.2, R9.1
/C1: J3.2, R11.1
/C2: J3.3, R13.1
/C3: J3.4, R15.1
/RESTART: J1.15, R1.2, U1.3 (~RESET)
/RX R: J1.10, J2.3
/SCL: J1.5, R2.2, U1.22 (SCL), U3.10 (SCL)
/SCL_0: J9.3, U1.5 (SC0)
/SCL_1: J8.3, U1.7 (SC1)
/SCL_2: J11.3, U1.9 (SC2)
/SCL_3: J10.3, U1.11 (SC3)
/SDA: J1.3, R3.2, U1.23 (SDA), U3.9 (SDA)
/SDA_0: J9.4, U1.4 (SD0)
/SDA_1: J8.4, U1.6 (SD1)
/SDA_2: J11.4, U1.8 (SD2)
/SDA_3: J10.4, U1.10 (SD3)
/TX R: J1.8, J2.2
/servo_gpio: J1.12, J4.3
GND: C1.2, C4.2, C5.1, C7.2, C8.2, C9.2, D2.2 (A), J1.6, J2.1, J3.1, J4.2, J5.2, J6.2, J7.2, J8.2, J9.2, J10.2, J11.2, R5.2, R6.2, R7.2, R8.2, R12.2, R14.2, R16.2, U1.1 (A0), U1.2 (A1), U1.12 (GND), U1.21 (A2), U2.5 (GND), U3.3 (GND); also elsewhere on the board
unnamed: C2.2, R7.1
unnamed: C3.1, D2.1 (K), L1.1, U2.1 (SW)
unnamed: J5.1, Q1.3 (S), R10.1
unnamed: J7.1, Q1.1 (G), R10.2
unnamed: C3.2, U2.8 (BST)
unnamed: C2.1, U2.3 (COMP)
unnamed: R4.2, R5.1, U2.2 (EN)
unnamed: R8.1, R9.2, U2.4 (FB)
unnamed: R6.1, U2.6 (FREQ)
unnamed: R11.2, R12.1, U3.4 (AIN0)
unnamed: R13.2, R14.1, U3.5 (AIN1)
unnamed: R15.2, R16.1, U3.6 (AIN2)

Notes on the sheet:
POGO Pins
11.1V 850mAh
Battery Percent
11.1V to 5V
Resberry Pi Zero 2 W
Lipo battery & POGO Pins
Darwin F411 AIO
4x ToF
Servomotor

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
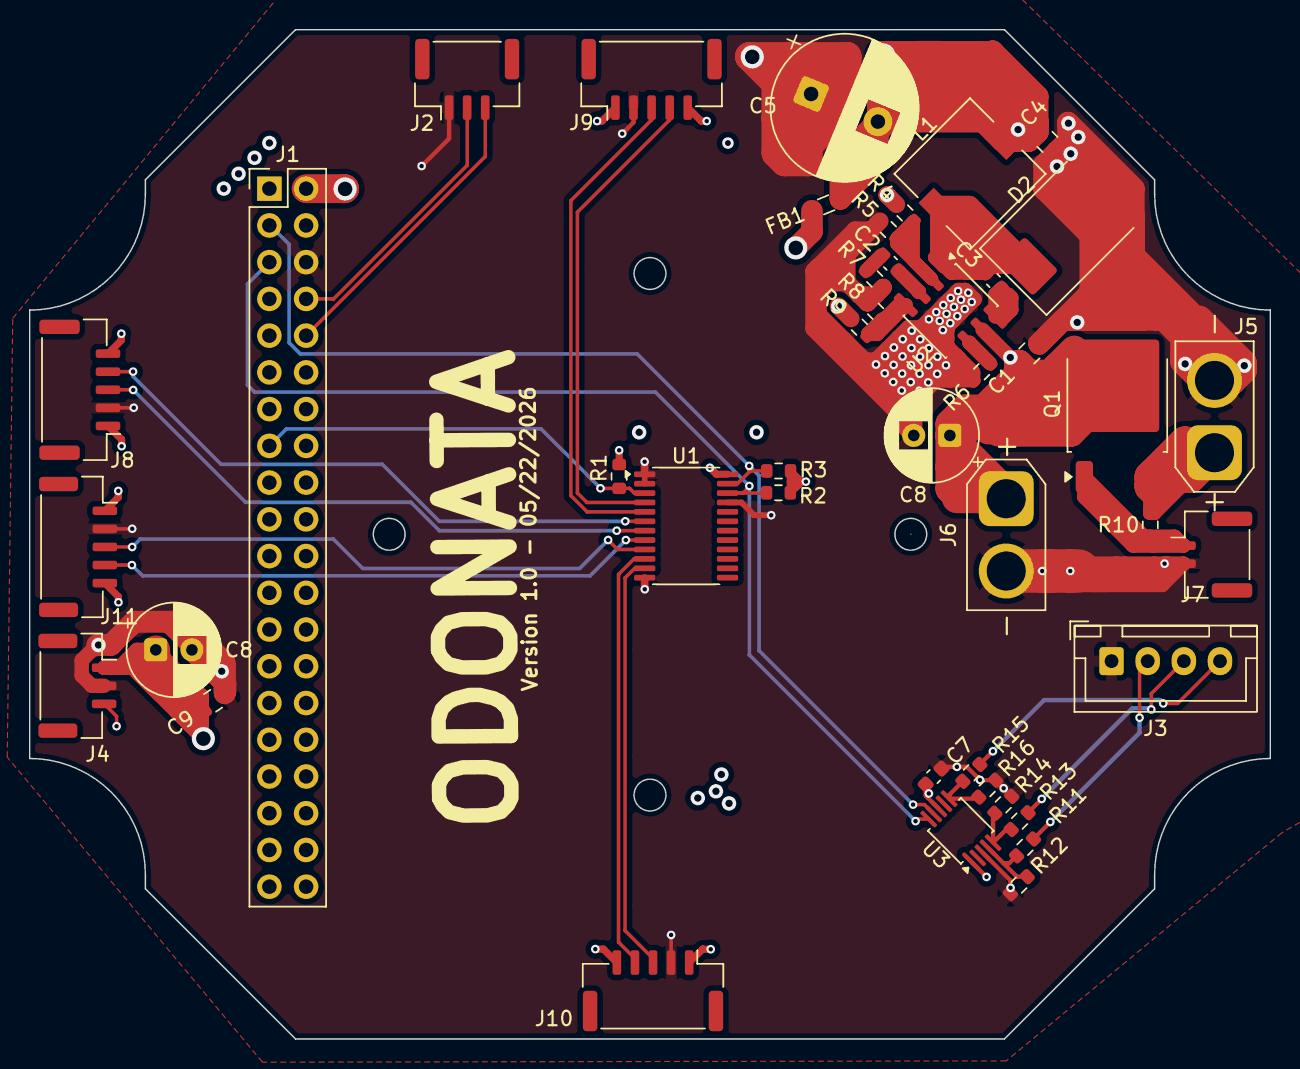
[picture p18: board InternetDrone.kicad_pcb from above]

Board: 4 copper layers, 85.8 x 69.8 mm, 43 parts (0 on the bottom side), 34 nets.

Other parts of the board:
C8#2: 100uF; CP_Radial_D6.3mm_P2.50mm

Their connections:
GND: C8#2.2; also elsewhere on the board

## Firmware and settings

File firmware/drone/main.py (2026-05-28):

"""
1. make ssh connection with the drone
2. install mav proxy
3. setup fc wiht mission planner, to enable the UR ports
4.  set the boud rate to 115200 +set the protocol to mavlink 2
5. make the connection between the pi and fc: 
    1. ssh connection to the pi
    2  cd .local/bin
    3.  python3 mavproxy.py -- master=/dev/serial0 -- baudrate 115200 -- aircraft MyCopter       <-- install maxproxy 
"""
# drone imports
from pymavlink import mavutil
from firmware.drone import motor, servo, camera, battery_status, tof_sensor
import time

# server imports
import fastapi
import uvicorn
from fastapi import FastAPI, BackgroundTasks, Request
from fastapi.responses import JSONResponse
from pydantic import BaseModel
import json
import uuid

try:
    from aiortc import RTCPeerConnection, RTCSessionDescription
    from firmware.drone.camera import CameraTrack
except ImportError:
    RTCPeerConnection = None
    RTCSessionDescription = None
    CameraTrack = None

# RTCPeerConnection handling
pcs = set()

# Initialize camera
cam = camera.Camera()
cam.setup()
cam.start()

# -- Functions to interact with the drone ---

def flight_loop():
    # start the drone and get the connection to the flight controller and arm
    master = turn_on_drone()
    motor.arm_drone(master)
    
    # take off to 1 meter altitude
    motor.takeoff_drone(master, target_altitude=1.0)

    # fly forward for 1 meter and then back
    for _ in range(2):
        # rotate the drone by 180 degrees
        motor.yaw_drone(master, yaw_rate=180, duration=2)

        # fly forward for 1 meter
        motor.move_drone(master, direction="front", speed=0.5, distance=1.0, stopping_distance=0.20)

    # land the drone
    motor.land_drone(master, landing_speed=0.25)

    # shutdown the drone and disconnect from the flight controller
    shutdown_drone(master)

def get_battery_status():
    return battery_status.get_battery_percentage()

def move_servo(angle):
    # move the servo to the desired angle
    servo.move_servo(angle)

def get_tof_distances():
    return tof_sensor.get_distances()

def test_motors(master, motor_number, throttle_value, time_seconds):
    motor.test_motor(master, motor_number, throttle_value, time_seconds)

def turn_on_drone():
    # build the connection to the flight controller
    master = mavutil.mavlink_connection('/dev/serial0', baud=115200)  

    # wait until the first heartbeat is received
    master.wait_heartbeat()
    print("Successfully connected to the flight controller")

    # here comes the logic of the drone

    return master

def shutdown_drone(master):
    """Shut down the drone"""
    # disconnet the motors
    master.arducopter_disarm()

    print("finished!")

    # disconnect the connection to the flight controller
    master.close()


# -- API endpoints ---

app = FastAPI()

class ServoCommand(BaseModel):
    angle: int

class MotorTestCommand(BaseModel):
    motor_number: int
    throttle: float
    duration: float

@app.get("/api/telemetry")
def api_get_telemetry():
    battery = 0
    try:
        battery = get_battery_status()
        tof = get_tof_distances()
    except Exception as e:
        print(f"Error occurred while fetching telemetry: {e}")
        return {
            "battery": battery,
            "tof": {
                "right": 0,
                "front": 0,
                "bottom": 0,
                "left": 0
            }
        }
    
    return {
            "battery": battery, 
            "tof": {
                "right": tof["right"],
                "front": tof["front"],
                "bottom": tof["bottom"],
                "left": tof["left"]
            }
        }

@app.post("/api/drone/start")
def api_start_drone():
    try:
        master = turn_on_drone()
        motor.arm_drone(master)
        return {"status": "Drone started successfully"}
    except Exception as e:
        print(f"Error occurred while starting the drone: {e}")
        return {"status": "Failed to start drone"}
    
@app.post("/api/drone/stop")
def api_stop_drone():
    try:
        master = turn_on_drone()
        shutdown_drone(master)
        return {"status": "Drone stopped successfully"}
    except Exception as e:
        print(f"Error occurred while stopping the drone: {e}")
        return {"status": "Failed to stop drone"}
    
@app.post("/api/flight/start")
def api_start_flight():
    try:
        # add a bg task to ensure the api loop keeps running while the flight loop is executed in the background
        fastapi.background_tasks.add_task(flight_loop)
        return {"status": "Flight started successfully"}
    except Exception as e:
        print(f"Error occurred while starting the flight: {e}")
        return {"status": "Failed to start flight"}
    
@app.post("/api/servo/move")
def api_move_servo(command: ServoCommand):
    try:
        move_servo(command.angle)
        return {"status": f"Servo moved to angle {command.angle} successfully"}
    except Exception as e:
        print(f"Error occurred while moving the servo: {e}")
        return {"status": "Failed to move servo"}
    
@app.post("/api/motor/test")
def api_test_motor(command: MotorTestCommand):
    try:
        master = turn_on_drone()
        test_motors(master, command.motor_number, command.throttle, command.duration)
        shutdown_drone(master)
        return {"status": "success"}
    except Exception as e:
        print(f"Error occurred while testing the motor: {e}")
        return {"status": "Failed to test motor"}

class WebRTCOffer(BaseModel):
    sdp: str
    type: str

@app.post("/api/webrtc/offer")
async def webrtc_offer(offer: WebRTCOffer):
    if RTCPeerConnection is None:
        return JSONResponse(content={"error": "aiortc is not installed"}, status_code=500)
    
    pc = RTCPeerConnection()
    pcs.add(pc)

    @pc.on("connectionstatechange")
    async def on_connectionstatechange():
        print(f"Connection state is {pc.connectionState}")
        if pc.connectionState == "failed" or pc.connectionState == "closed":
            await pc.close()
            pcs.discard(pc)

    # Add the camera video track
    video_track = CameraTrack(cam)
    pc.addTrack(video_track)

    desc = RTCSessionDescription(sdp=offer.sdp, type=offer.type)
    await pc.setRemoteDescription(desc)
    answer = await pc.createAnswer()
    await pc.setLocalDescription(answer)

    return JSONResponse(
        content={"sdp": pc.localDescription.sdp, "type": pc.localDescription.type}
    )

@app.on_event("shutdown")
async def on_shutdown():
    # close all peer connections
    coros = [pc.close() for pc in pcs]
    import asyncio
    await asyncio.gather(*coros)
    cam.stop()

if __name__ == "__main__":
    uvicorn.run(app, host="0.0.0.0", port=5000)

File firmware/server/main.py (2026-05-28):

from os import path
import requests
from fastapi import FastAPI, Request
from fastapi.responses import HTMLResponse
from fastapi.templating import Jinja2Templates
from fastapi.staticfiles import StaticFiles
from pydantic import BaseModel
from pymavlink import mavutil

import requests

app = FastAPI(title="Drone Control Cockpit")

import subprocess
import socket
import re
import platform

# define the frontend
if path.exists("frontend"):
    app.mount("/static", StaticFiles(directory="frontend/static"), name="static")

templates = Jinja2Templates(directory="frontend")


# defining the API adresses of the drone
pi_ip = ""
pi_url = f"http://{pi_ip}:5000/api"

class ServoCommand(BaseModel):
    angle: int

class MotorTestCommand(BaseModel):
    motor_number: int
    throttle: float
    duration: float

class DroneIPCommand(BaseModel):
    ip: str

@app.get("/", response_class=HTMLResponse)
def index(request: Request):
    return templates.TemplateResponse(request, "index.html")

@app.get("/api/connected-ips")
def get_connected_ips():
    devices = []
    try:
        # Run arp -a to get neighbor cache
        output = subprocess.check_output("arp -a", shell=True).decode(errors="ignore")
        # Extract IP addresses using regex
        ips = re.findall(r"\b(?:[0-9]{1,3}\.){3}[0-9]{1,3}\b", output)
        
        # Remove duplicates and multicast/broadcast addresses
        unique_ips = list(set(ips))
        for ip in unique_ips:
            if ip.startswith("127.") or ip.startswith("224.") or ip.startswith("239.") or ip.endswith(".255"):
                continue
            
            # try to get hostname as description
            try:
                hostname = socket.gethostbyaddr(ip)[0]
            except socket.herror:
                hostname = "Unknown Device"
            
            devices.append({"ip": ip, "description": hostname})
    except Exception as e:
        print(f"Error scanning network: {e}")
        
    return {"ips": devices}

@app.post("/api/set-drone-ip")
def set_drone_ip(command: DroneIPCommand):
    global pi_ip, pi_url
    pi_ip = command.ip
    pi_url = f"http://{pi_ip}:5000/api"
    return {"status": "success", "message": f"Drone IP set to {pi_ip}"}

# -- API telemetry ---
def get_telemetry():
    try:
        response = requests.get(f"{pi_url}/telemetry", timeout=1)
        data = response.json()

        # tof data
        pi_tof = data.get("tof", [0, 0, 0, 0])

        # 
        return {
            "battery": data.get("battery", 0),
            "tof": {
                "right": pi_tof[0] / 10, # convert from mm to cm
                "front": pi_tof[1] / 10,
                "bottom": pi_tof[2] / 10,
                "left": pi_tof[3] / 10
            }
        }
    except Exception as e:
        print(f"Error occurred while fetching telemetry: {e}")
        return {
            "battery": 0,
            "tof": {
                "right": 0,
                "front": 0,
                "bottom": 0,
                "left": 0
            }
        }

# -- API commands ---

@app.post("/api/drone/start")
def start_drone():
    try:
        response = requests.post(f"{pi_url}/drone/start", timeout=1)
        return response.json()
    except Exception as e:
        print(f"Error occurred while starting the drone: {e}")
        return {"status": "error", "message": "Failed to start the drone and to reach the raspberry pi"}
    
@app.post("/api/drone/stop")
def stop_drone():
    try:
        response = requests.post(f"{pi_url}/drone/stop", timeout=1)
        return response.json()
    except Exception as e:
        print(f"Error occurred while stopping the drone: {e}")
        return {"status": "error", "message": "Failed to stop the drone and to reach the raspberry pi"}
    
@app.post("/api/flight/start")
def start_flight():
    try:
        response = requests.post(f"{pi_url}/flight/start", timeout=1)
        return response.json()
    except Exception as e:
        print(f"Error occurred while starting the flight: {e}")
        return {"status": "error", "message": "Failed to start the flight and to reach the raspberry pi"}
    
class WebRTCOffer(BaseModel):
    sdp: str
    type: str

@app.post("/api/webrtc/offer")
def webrtc_offer(offer: WebRTCOffer):
    try:
        response = requests.post(f"http://{pi_ip}:5000/api/webrtc/offer", json={"sdp": offer.sdp, "type": offer.type}, timeout=3)
        if response.status_code == 200:
            return response.json()
        return {"error": f"Failed with status {response.status_code}"}
    except Exception as e:
        print(f"Error occurred while starting webrtc: {e}")
        return {"error": "Failed to connect to the drone for WebRTC"}

@app.post("/api/servo/move")
def move_servo(command: ServoCommand):
    try:
        response = requests.post(f"{pi_url}/servo/move", json={"angle": command.angle}, timeout=1)
        return {"status": "success", "message": f"Servo moved to {command.angle} degrees"}
    except Exception as e:
        print(f"Error occurred while moving the servo: {e}")
        return {"status": "error", "message": "Failed to move the servo and to reach the raspberry pi"}
    
@app.post("/api/motor/test")
def test_motor(command: MotorTestCommand):
    try:
        response = requests.post(f"{pi_url}/motor/test", json=command.dict(), timeout=1)
        return {"status": "success", "message": f"Motor {command.motor_number} tested with throttle {command.throttle} for {command.duration} seconds"}
    except Exception as e:
        print(f"Error occurred while testing the motor: {e}")
        return {"status": "error", "message": "Failed to test the motor and to reach the raspberry pi"}

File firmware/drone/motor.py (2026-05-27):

from pymavlink import mavutil
import tof_sensor
import time
import math
from camera import Camera as cam

def arm_drone(master):
    """
    Arm the drone by sending the appropriate command to the flight controller.
    
    """
    print("Arming motors...")
    master.mav.command_long_send(
        master.target_system, master.target_component,
        mavutil.mavlink.MAV_CMD_COMPONENT_ARM_DISARM, 0,
        1, 0, 0, 0, 0, 0, 0
    )
    time.sleep(2) # Give motors time to spin up safely


def test_motor(master, motor_number, throttle_value, time_seconds):
    """
    Test a specific motor by sending a motor test command.

    :param motor_number: the number of the motor to test (1-4)
    :param throttle_value: the throttle value in percentage (0-100)
    :param time_seconds: the duration of the test in seconds
    """
    # activate the motors
    arm_drone(master)

    master.mav.command_long_send(
        1, # system id of the fc
        0, # autopilot mode of the fc
        mavutil.mavlink.MAV_CMD_DO_MOTOR_TEST, 
        0, # confirmation
        motor_number, # motor number
        0, # throttle  in percentage 
        throttle_value, # throttle value in percentage
        time_seconds, # time in seconds of the test
        0, # -
        0, # -
        0  # -
    )


def takeoff(master, target_altitude=1.0, climbing_speed=0.3):
    """
    here we need sensor number 2 (one that is facing downwards) to measure the distance to the ground, and then we can use that distance to take off to a certain height

    :param target_altitude: the target altitude in meters
    :param climbing_speed: the climbing speed in m/s
    """
    # changing to GUIDED_NOGPS mode, to be able to control the drone without gps
    master.set_mode('GUIDED_NOGPS')

    # wait a bit to ensure the mode is changed
    time.sleep(1)

    # activate the motors
    arm_drone(master)

    # convert the target altitude int milimeters, because the distance from the sensor is measured in milimeters
    target_altitude_mm = target_altitude * 1000

    # chnaging climbing speed to negative, beacause the mavlinkt takes negative values for climbing up and positive values for climbing down
    climb_speed = -abs(climbing_speed)

    print(f"Taking off to {target_altitude} meters with climbing speed of {climbing_speed} m/s")

    while True:
        distance = tof_sensor.get_distances()[2] # get the distance from the sensor number 2, which is facing downwards

        if distance >= target_altitude_mm*0.95: # if the drone is at 95% of the target altitude, we can stop climbing
            print(f"Reached target altitude of {target_altitude} meters")
            break

        master.mav.set_position_target_local_ned_send(
            0, # time_boot_ms
            master.target_system, master.target_component,
            mavutil.mavlink.MAV_FRAME_LOCAL_NED,
            0b0000110111000111, # type_mask (only vertical velocity is enabled)
            0, 0, 0, # x, y, z positions (not used)
            0, 0, climb_speed, # x, y, z velocity in m/s
            0, 0, 0, # x, y, z acceleration (not used)
            0, 0 # yaw, yaw_rate (not used)
        )
        
        # wait a bit before the next command <- drone is controlled every 100ms
        time.sleep(0.1) 

    # now the drone has to hover in that position
    print("Entering hover mode")

    # changing to ALT_HOLD mode, to be able to hover in that position
    master.set_mode('ALT_HOLD')

    # wait a bit to ensure the mode is changed
    time.sleep(1)


def move_drone(master, direction="front", speed=0.5, distance=1.0, stopping_distance=0.5):
    """
    :param direction: the direction in which the drone should move, can be "front", "back", "left" or "right"
    :param speed: the speed at which the drone should move in m/s
    :param distance: the distance the drone should move in meters
    :param tof_sensors: the list of the tof sensors, which are used to measure the distance to the obstacles in the corresponding direction, and they are in the order of the channels (0, 1, 2, 3)
    :param stopping_distance: the distance at which the drone should stop in meters
    """

    # initialize the velocity values for the x and y direction
    vy, vx = 0.0, 0.0

    # activate the no_gps mode, to be able to control the drone without gps
    master.set_mode('GUIDED_NOGPS')
    time.sleep(1) # wait a bit to ensure the mode is changed

    if direction == "front":
        vy = speed
        sensor_index = 1
    elif direction == "back":
        vy = -speed
        sensor_index = None # we don't have a sensor facing backwards, so we can't measure the distance to obstacles in that direction, the drone has to yaw firstly and then it will move
        return 
    elif direction == "left":
        vx = -speed
        sensor_index = 3
    elif direction == "right":
        vx = speed
        sensor_index = 0
    else:
        print("Invalid direction, please choose from 'front', 'back', 'left' or 'right'")
        return
    
    # calculate the time needed to move to the target distance with the given speed and time
    time_needed = distance / speed

    # start the timer to control the movement for the calculated time
    start_time = time.time()

    # here happens the real movment logic
    while True:
        elapsed_time = time.time() - start_time
        current_distance = tof_sensor.get_distances()[sensor_index]

        # if the sensor send a error value, becasue the distance is to far, we rely on the time to control the movement
        if current_distance == 8190 or current_distance == 8191 or current_distance == 0: 
            print("Distance measurement error, moving for the calculated time")

            # if the elapsed time is greater than or equal to the calculated time, we can stop the movement, because we reached the target distance
            if elapsed_time >= time_needed:
                print(f"Reached target distance of {distance} meters")
                break
        
        # if the sensor send valid distances, we use the distance control
        else:
            # if the current distance is less than or equal to the stopping distance, we stop the movement to avoid collision
            if current_distance <= distance*1000 or current_distance <= stopping_distance*1000: 
                print(f"Reached stopping distance of {stopping_distance} meters, stopping to avoid collision")
                break

        # here we will now happen the movement command
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

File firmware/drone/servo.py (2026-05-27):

from gpiozero import AngularServo
import time

# the gpio pin for the servo
gpio_pin = 18 

# safe angle range for the servo
min_angle = -90
max_angle = 90

# define the servo
servo = AngularServo(gpio_pin, min_angle=min_angle, max_angle=max_angle)

def calibrate_servo():
    # calibrate the servo
    servo.angle = 0
    time.sleep(1)

def move_servo(angle):
    """
    Move the servo to a specific angle within the safe range.
    
    :param angle: the desired angle to move the servo to, in degrees
    """

    # confirm and potentially adjust the angle to be within the safe zone
    safe_angle = max(min_angle, min(max_angle, angle)) # ensure the angle is within the safe range

    # move the servo to desired angle
    servo.angle = safe_angle

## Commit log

2026-05-25 Add main and motor scripts for drone firmware
2026-05-25 Refactor drone control logic and add motor activation function
2026-05-25 Add ToF sensor measurement functionality
2026-05-25 Add threading support to ToFSensor for distance measurement loop
2026-05-25 Refactor motor and ToFSensor classes to improve motor arming logic and enhance distance measurement handling
2026-05-25 Refactor main and motor modules to improve code structure and enhance takeoff logic
2026-05-26 Refactor takeoff function to remove unused altitude measurement and add placeholder for yaw_drone function
2026-05-26 Update README and requirements; add camera module for Raspberry Pi
2026-05-26 Add camera setup and AprilTag detection functionality
2026-05-26 Enhance camera module with multi-threaded AprilTag detection and configurable parameters
2026-05-26 Fix camera index in VideoCapture and add servo control functionality
    [camera.py, servo.py]
2026-05-26 Add battery status monitoring functionality
2026-05-27 Refactor battery status class and implement battery percentage calculation
2026-05-27 Fix battery percentage initialization and update voltage factor comment
    [battery_status.py]
2026-05-27 Add docstrings for camera, motor, and servo functions to improve code documentation
2026-05-27 Enhance move_drone function with velocity initialization, obstacle avoidance, and hover mode support
    [motor.py]
2026-05-27 Add yaw_drone function for controlled yaw movement and enhance move_drone collision avoidance
    [motor.py]
2026-05-27 Enhance yaw_drone function to include duration parameter for controlled yaw movement
2026-05-27 Implement land_drone function for controlled landing using camera and distance sensor data
2026-05-27 Refactor flight control logic and update land_drone function for improved landing speed
2026-05-27 Refactor flight control functions and enhance modularity by adding battery status, servo movement, and distance sensor functions
2026-05-27 Revamp frontend layout and styling for Odonata cockpit with new HTML structure, CSS dark theme, and enhanced JavaScript functionality for video streaming and motor controls
2026-05-27 Refactor cockpit layout and styling for improved user interface, including updated header structure, action buttons, and dashboard organization
2026-05-28 Implement API commands for drone control, including start, stop, flight initiation, servo movement, and motor testing with error handling
    [main.py]
2026-05-28 Add API endpoints for drone control and telemetry, including start, stop, servo movement, and motor testing
2026-05-28 Add frontend JavaScript and CSS for cockpit interface, including video stream and motor controls
2026-05-28 Add gerber files for PCB layout in zip format
    [InternetDrone.kicad_pcb, InternetDrone.kicad_sch]
2026-05-29 Adding the CAD files
    [april_tag_holder.f3d, april_tag_holder.step, april_tag_holder.stl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]
2026-05-29 Add LFS CAD files
2026-05-29 add cad
    [drone_assembly.step]
2026-05-29 Move CAD files to LFS only
    [drone_assembly.f3z, drone_assembly.step]
2026-05-30 Add drone assembly CAD file to LFS
    [drone_assembly.f3z]
2026-05-30 add BOM.csv
    [BOM.csv]
2026-05-30 Update BOM.csv and README.md with additional components and detailed project description; add firmware documentation and new images for the Odonata project.
    [BOM.csv]
2026-05-30 Update README.md with step-by-step build instructions and add new components to BOM; include AprilTag print PDF
    [BOM.csv]
